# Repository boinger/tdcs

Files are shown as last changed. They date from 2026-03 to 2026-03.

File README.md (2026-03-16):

# tDCS — Open Source Transcranial Direct Current Stimulation

Board layout

A complete, open-source hardware design for a transcranial direct
current stimulation (tDCS) device. The board uses an LM334Z current
regulator with a trimmer potentiometer to deliver an adjustable
0.5-2 mA constant current through sponge electrodes. Designed in
KiCad, fabrication-ready gerbers included for
[OSH Park](https://oshpark.com).

## Disclaimer

**This is an experimental device, not a medical device.** The authors
are not medical professionals. Use entirely at your own risk. Do not
treat this project as medical advice. Passing electric current through
your brain carries inherent risks. Read the published literature and
understand the schematics before attempting anything.

## Getting Started

**Prerequisites:** [KiCad](https://www.kicad.org/) 9.0 or later.

```bash
# macOS
brew install --cask kicad

# Linux (Ubuntu/Debian)
sudo apt install kicad
```

```bash
git clone https://github.com/boinger/tdcs
```

## Workflow

1. Open `tdcs.kicad_sch` in KiCad Schematic Editor — review/edit the circuit
2. Open `tdcs.kicad_pcb` in KiCad PCB Editor
3. **Tools → Update PCB from Schematic** to import components
4. Place components and route traces (reference `board.png` for original layout)
5. Run DRC (**Inspect → Design Rules Checker**)
6. Generate gerbers: `cd gerbers && ./generate-gerbers.sh`

### CLI Commands

```bash
# Export schematic as PDF
kicad-cli sch export pdf -o tdcs-schematic.pdf tdcs.kicad_sch

# Export BOM
kicad-cli sch export bom -o bom.csv tdcs.kicad_sch

# Export netlist
kicad-cli sch export netlist -o board.net tdcs.kicad_sch

# Run ERC (Electrical Rules Check)
kicad-cli sch erc tdcs.kicad_sch

# Generate gerbers (after PCB layout is complete)
cd gerbers && ./generate-gerbers.sh
```

## Getting the PCB Made

1. Upload `gerbers/tdcs.zip` to [OSH Park](https://oshpark.com) (or
   your preferred fab house).
2. Order parts from `bom.csv`.

## Accessories

Beyond the PCB and BOM components, you'll need:

- **Sponge electrodes** — the only electrode type with low enough
  impedance for reliable 2 mA delivery
- **Electrode cables** — speaker cable or lamp cord works fine
- **Pin connectors or banana plugs** — or solder cables directly to
  the board
- **12 V DC power supply** via barrel connector (or a 9 V battery
  if you only need up to ~1 mA)

## Safety

Liebetanz et al. (2009) established a brain-lesion threshold in rats
of **142.9 A/m²** sustained for >10 minutes
([DOI: 10.1016/j.clinph.2009.01.022](https://doi.org/10.1016/j.clinph.2009.01.022)).

This design uses 25 cm² sponge electrodes. Current densities:

| Condition | Current | Density | vs. Threshold |
|---|---|---|---|
| Normal operation | 2 mA | 0.8 A/m² | ~0.6% |
| Regulator failure (max) | 3 mA | 1.2 A/m² | ~0.8% |

Both cases are well below the damage threshold by two orders of
magnitude.

## Other Designs

The original upstream repo has branches for two additional designs:

- **v2** — MSP430-based programmable stimulator with USB power, data
  logging, and software-controlled current (via AD8400 digital pot)
- **v3** — Simplified USB-powered fixed-output (2 mA) stimulator

See [historical/](historical/) for archived blog posts describing
these designs.

## Repository Structure

| Path | Purpose |
|---|---|
| `tdcs.kicad_sch` | Main schematic (KiCad Schematic Editor) |
| `tdcs.kicad_pcb` | Board layout (KiCad PCB Editor) |
| `tdcs.kicad_pro` | KiCad project file |
| `gerbers/` | Gerber output + `generate-gerbers.sh` |
| `gerbers/tdcs.zip` | Ready-to-upload zip for OSH Park |
| `datasheets/` | Component datasheets |
| `historical/` | Archived upstream blog posts, images, and gEDA design files |

## License

All files are licensed
[CC-BY 3.0](https://creativecommons.org/licenses/by/3.0/).
Full text in [LICENSE.txt](LICENSE.txt). Original design by
[Shawn Nock](https://github.com/nocko).

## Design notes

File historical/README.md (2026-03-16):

# Historical Reference Materials

Original design by [Shawn Nock](https://github.com/nocko) (nocko),
published July-August 2012. Upstream repo:
[nocko/tdcs](https://github.com/nocko/tdcs).

These materials were recovered from the Wayback Machine after the
original blog at nocko.se went offline. Archived for provenance and
historical reference.

## Blog Posts (Wayback Machine HTML captures)

- **blog-v1-brain-zapping-is-fun.html** — "Open Source Hardware TDCS"
  (July 30, 2012). Introduces the v1 design, accessories list, and
  safety analysis.
  [Wayback link](https://web.archive.org/web/20160320002608/https://nocko.se/2012/07/30/brain-zapping-is-fun/)

- **blog-v2v3-two-new-designs.html** — "Two new Open tDCS designs"
  (August 8, 2012). Describes the v2 (MSP430 programmable) and v3
  (USB simple) designs.
  [Wayback link](https://web.archive.org/web/20160511003744/https://nocko.se/2012/08/08/opentdcs/)

## Images

- `v1-schematic.png` — v1 circuit diagram (LM334Z current regulator)
- `v1-board-front.png` — v1 PCB front render (OSH Park)
- `v1-board-back.png` — v1 PCB back render (OSH Park)
- `v2-schematic.png` — v2 circuit diagram (MSP430 + FT232RL + AD8400)

## gEDA Design Files (`geda/`)

The original v1 design was created in gEDA. These files were moved
here when the project was ported to KiCad. They are the canonical
source for the original circuit and PCB layout.

- `tdcs.sch` — Main schematic (gschem format)
- `tdcs.pcb` — Board layout (gEDA PCB format)
- `project` — gsch2pcb config: schematics list, output name
- `gafrc` — gschem config: custom symbol library paths
- `attribs` — BOM field template for gnetlist
- `board.cmd` — Pin renaming commands applied during PCB import
- `generate-gerbers.sh.orig` — Original gEDA-based gerber generation script
- `gschem-sym/` — Custom schematic symbols:
  - `current-reg/lm334-1.sym` — LM334Z current regulator (used in v1)
  - `lt1026-1.sym` — LT1026 charge pump (used in v1)
  - `n-jfet.sym` — N-channel JFET (used in v1)
  - `ad6400.sym` — AD6400 (v2 design, unused in v1)
  - `dpst-1.sym` — DPST switch (unused in v1)
  - `ft232rl.sym` — FT232RL USB-to-serial (v2 design, unused in v1)
  - `msp430f21x2-1.sym` — MSP430 microcontroller (v2 design, unused in v1)
  - `st662ab.sym` — ST662AB charge pump (unused in v1)
  - `usbconn.sym` — USB connector (v2/v3 design, unused in v1)
  - `ZXCT1009.sym` — ZXCT1009 current monitor (unused in v1)

## Unused Footprints (`unused-footprints/`)

Custom PCB footprints from earlier design iterations (v2/v3). None are
referenced by the current v1 schematic. Moved here from `packages/`.

- `ct6ep-2.fp` — Copal CT6EP trimmer (alternate footprint)
- `EG 1218-1.fp` — E-Switch toggle
- `Emerson Test Port horizontal.fp` — Emerson test port (horizontal)
- `Emerson Test Port.fp` — Emerson test port (vertical)
- `mill max mini-usb.fp` — Mill-Max mini-USB connector
- `PJ-031D-2.fp` — CUI barrel jack (variant 2)
- `PJ-031D-3.fp` — CUI barrel jack (variant 3)
- `PJ-031D.fp` — CUI barrel jack
- `SJ1-352xN.fp` — CUI 3.5mm audio jack

## Unused Datasheets (`unused-datasheets/`)

Datasheets for components used in v2/v3 designs but not in the current
v1 board. Moved here from `datasheets/`.

- `AD8400_8402_8403.pdf` — Analog Devices digital potentiometer (v2 design)
- `DS_FT232R.pdf` — FTDI FT232R USB-to-serial (v2 design)

## License

All original materials by Shawn Nock are licensed
[CC-BY 3.0](https://creativecommons.org/licenses/by/3.0/).

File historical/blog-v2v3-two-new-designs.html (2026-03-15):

Wayback Machine

8 captures

20 Sep 2015 - 12 Nov 2020

Apr | MAY | Jun
| 11
2015 | 2016 | 2017

success

fail

(https://archive.org/account/login.php) (https://help.archive.org/help/category/the-wayback-machine/)

About this capture

COLLECTED BY

Organization: Internet Archive (https://archive.org/details/webwidecrawl)

The Internet Archive discovers and captures web pages through many different web crawls. At any given time several distinct crawls are running, some for months, and some every day or longer. View the web archive through the Wayback Machine (http://archive.org/web/web.php).

Collection: Wide Crawl Number 14 - Started Mar 4th, 2016 - Ended Sep 15th, 2016 (https://archive.org/details/wide00014)

The seed for Wide00014 was:

- Slash pages from every domain on the web:

-- a list of domains using Survey crawl seeds

-- a list of domains using Wide00012 web graph

-- a list of domains using Wide00013 web graph

- Top ranked pages (up to a max of 100) from every linked-to domain using the Wide00012 inter-domain navigational link graph

-- a ranking of all URLs that have more than one incoming inter-domain link (rank was determined by number of incoming links using Wide00012 inter domain links)

-- up to a maximum of 100 most highly ranked URLs per domain

The seed list contains a total of 431,055,452 URLs
The seed list was further filtered to exclude known porn, and link farm, domains
The modified seed list contains a total of 428M URLs

TIMESTAMPS

loading

The Wayback Machine - https://web.archive.org/web/20160511003744/https://nocko.se/2012/08/08/opentdcs/

Shawn Nock

- About
- Computing
- tDCS

# Two new Open tDCS designs

I think the clever bit was re-purposing the flash memory voltage regulator to power the circuits entirely from USB. Also the electrode interface has been changed to a standard headphone jack. It’ll make it easier to design a case (also, hackers can save money reusing old connectors).

## Version 2: A full-featured programmable stimulator

v2 Schematic

The schematic and incomplete board layout is available in the v2 branch of the Open tTDCS repository (https://web.archive.org/web/20160511003744/https://github.com/nocko/tdcs/tree/v2). The potential feature set is huge:

- Powered and programmed via USB
- Data logging and runtime control via USB
- Programmable current ramping and switching
- Precision current and voltage monitoring
- Auto-trimming of current
- Battery operation available via Minty Boost (https://web.archive.org/web/20160511003744/http://www.ladyada.net/make/mintyboost/) or similar

There is a lot of work to complete before this will be usable. Specifically:

- MSP430 software needs to be written
- Squeezing the design into a 2 layer board is proving challenging
- Hobbyists may be deterred by high part count and SMT parts.

In the next week or two I’ll get the board designed and order prototypes.

## Version 3: USB powered, Simple Stimulator

v3 Board

I designed this board to output 2mA (trimmable +-10%) to be powered by USB with a minimal part count. It’s easy to use and has the following advantages:

- It’s cheap, $8.72/ea.
- It outputs exactly what you probably want, 2mA.
- It’s easy to use. Simply attach electrodes, then plug into USB port.

While I was developing v2, I started wondering if switching noise from the charge pump would effect the current ripple of the LM334Z. With the giant output capacitor I am not too worried, but this design started as a cheap way to check. As it evolved, I think it’s a good choice for a plug-and-play tDCS solution for those who just want cheap, easy and reliable current delivery for home use.

v3 Schematic

Schematic and pcb layout are available in the v3 branch of the Open tTDCS repository (https://web.archive.org/web/20160511003744/https://github.com/nocko/tdcs/tree/v3). I’ve ordered the prototypes and will update with results / scope images.

## How to Build

If you want to build the v3, simply zip the files in the gerber directory and upload to your pcb manufacturer of choice (I use oshpark (https://web.archive.org/web/20160511003744/http://oshpark.com/)). Order the parts listed in bom.txt (https://web.archive.org/web/20160511003744/https://github.com/nocko/tdcs/blob/v3/bom.txt). Solder the parts according to the instructions, and you’re good to go.

- ← Previous
- Archive
- Next →

#### Published

08 August 2012

#### Tags

- tdcs 2
- usb 1
- opentdcs 1

© Shawn Nock 2015

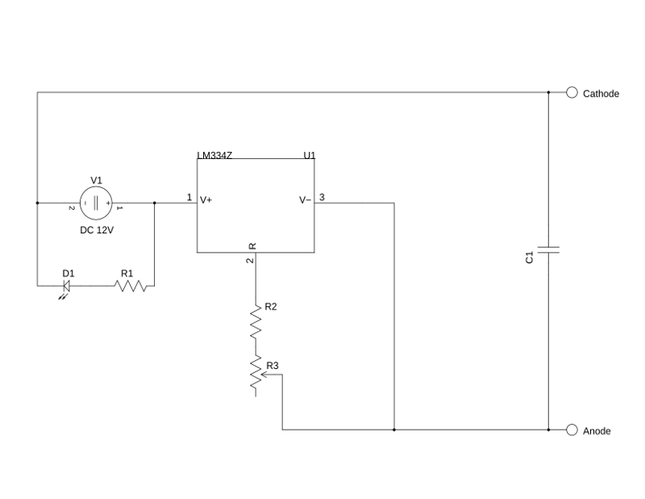
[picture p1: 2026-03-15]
historical/v1-schematic.png

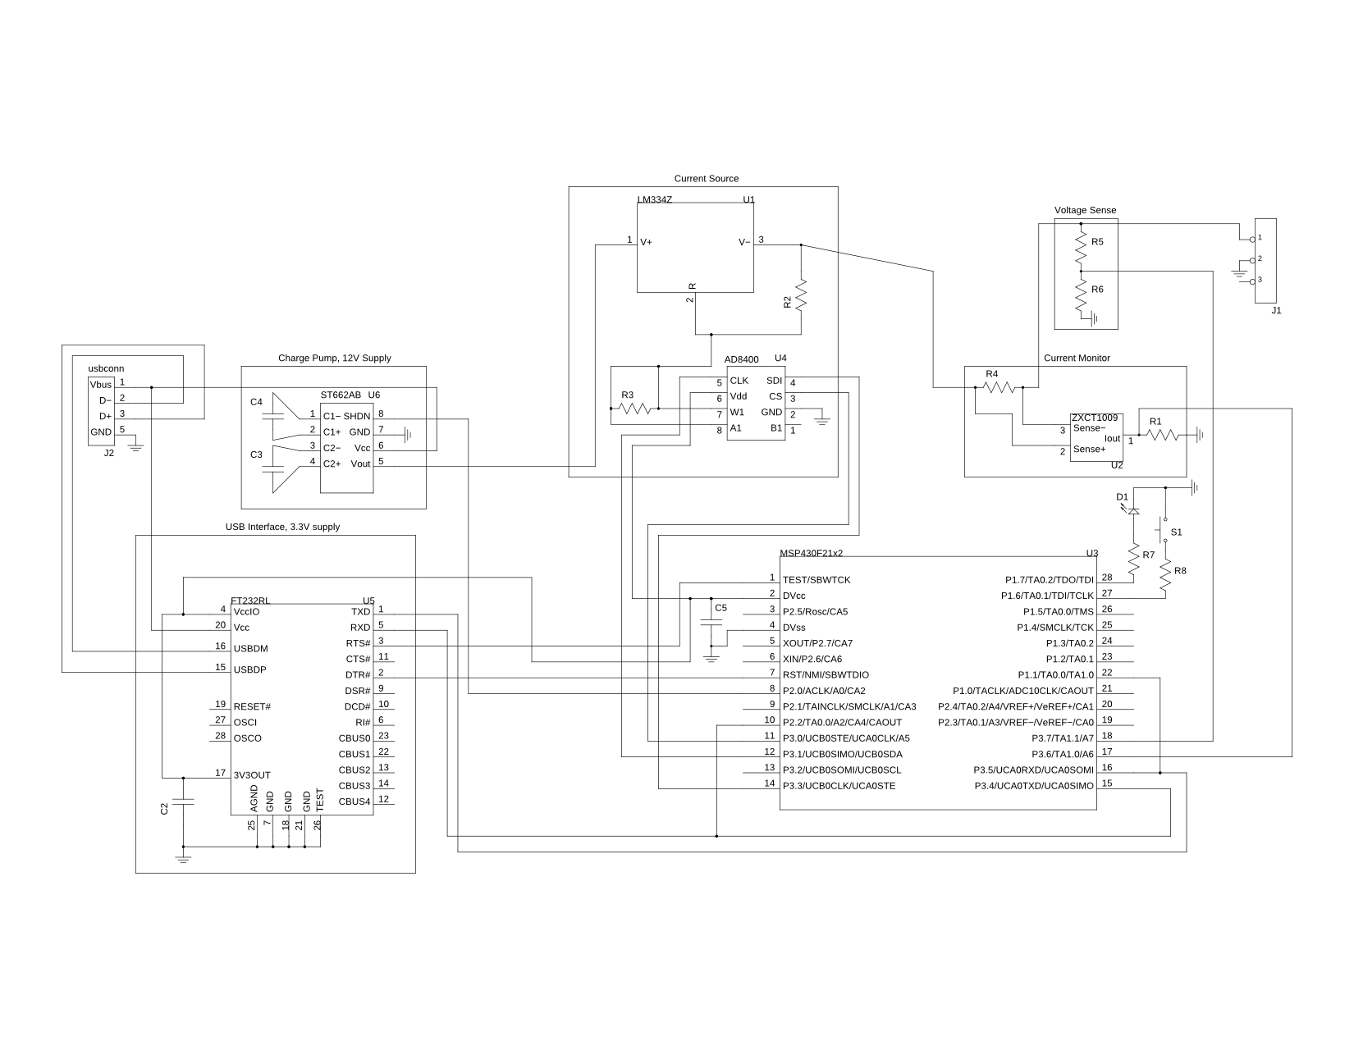
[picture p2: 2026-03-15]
historical/v2-schematic.png

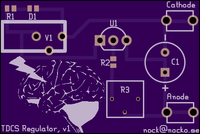
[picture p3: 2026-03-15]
historical/v1-board-front.png

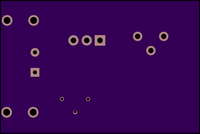
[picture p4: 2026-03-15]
historical/v1-board-back.png

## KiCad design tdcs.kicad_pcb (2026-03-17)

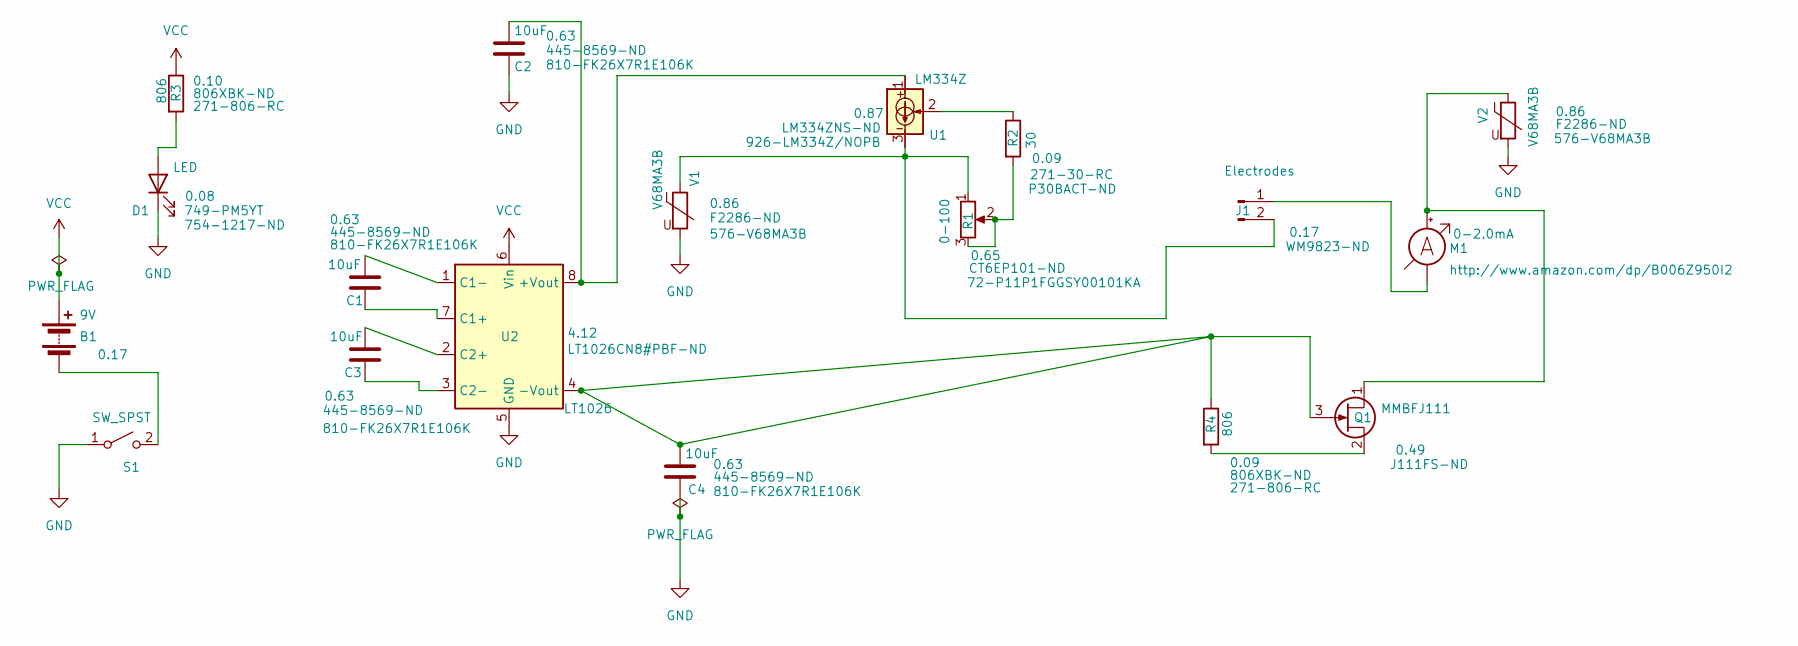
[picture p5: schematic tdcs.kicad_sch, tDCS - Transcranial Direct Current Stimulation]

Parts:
B1: 9V; PinHeader_1x02_P2.54mm_Vertical
C1, C2, C3, C4: 10uF; C_Disc_D5.0mm_W2.5mm_P5.00mm; DigiKey 445-8569-ND
D1: LED; LED_D3.0mm; DigiKey 754-1217-ND
J1: Electrodes; PinHeader_1x02_P2.54mm_Vertical; DigiKey WM9823-ND
M1: 0-2.0mA; PinHeader_1x02_P2.54mm_Vertical
Q1: MMBFJ111; TO-92_Inline; DigiKey J111FS-ND
R1: 0-100; PinHeader_1x03_P2.54mm_Vertical; DigiKey CT6EP101-ND
R2: 30; R_Axial_DIN0207_L6.3mm_D2.5mm_P7.62mm_Horizontal; DigiKey P30BACT-ND
R3, R4: 806; R_Axial_DIN0207_L6.3mm_D2.5mm_P7.62mm_Horizontal; DigiKey 806XBK-ND
S1: SW_SPST; PinHeader_1x02_P2.54mm_Vertical
U1: LM334Z; TO-92_Inline; DigiKey LM334ZNS-ND
U2: LT1026; DIP-8_W7.62mm; DigiKey LT1026CN8#PBF-ND
V1, V2: V68MA3B; R_Axial_DIN0207_L6.3mm_D2.5mm_P7.62mm_Horizontal; DigiKey F2286-ND

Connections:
GND: C2.2, C4.2, D1.1 (K), S1.1 (A), U2.5 (GND), V1.2, V2.2
unnamed: B1.2 (-), S1.2 (B)
unnamed: D1.2 (A), R3.2
unnamed: J1.1, M1.1 (-)
unnamed: J1.2, R1.1, U1.3, V1.1
unnamed: M1.2 (+), Q1.1 (D), V2.1
unnamed: C4.1, Q1.3 (G), R4.1, U2.4 (-Vout)
unnamed: Q1.2 (S), R4.2
unnamed: R1.2, R1.3, R2.2
unnamed: R2.1, U1.2
unnamed: C2.1, U1.1, U2.8 (+Vout)
unnamed: C1.2, U2.7 (C1+)
unnamed: C1.1, U2.1 (C1-)
unnamed: C3.1, U2.2 (C2+)
unnamed: C3.2, U2.3 (C2-)
VCC: B1.1 (+), R3.1, U2.6 (Vin)

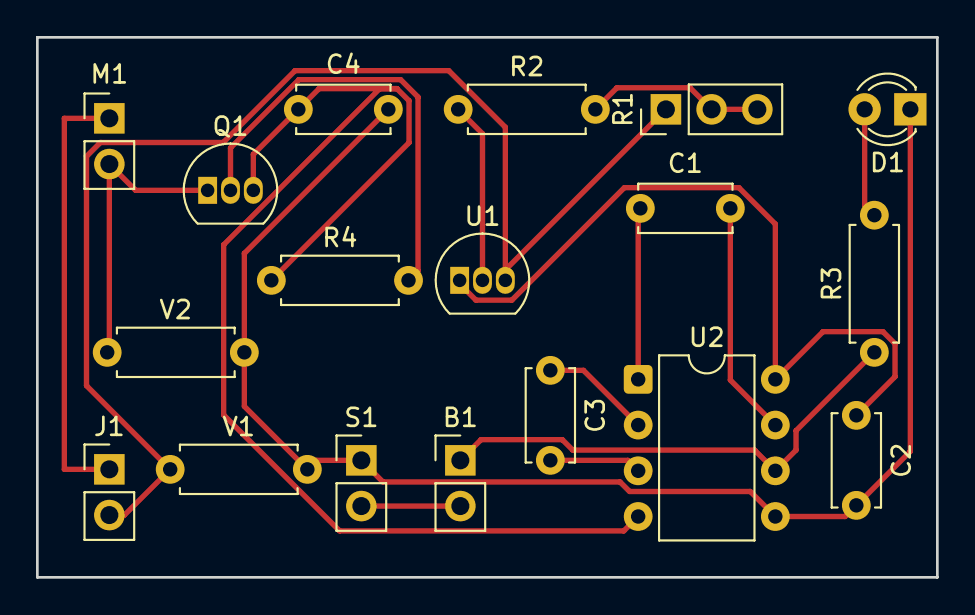
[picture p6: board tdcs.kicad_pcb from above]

Board: 2 copper layers, 50.0 x 30.0 mm, 18 parts (0 on the bottom side), 16 nets.

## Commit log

2026-03-15 Rewrite README, fix paths, archive upstream materials
    - Full README rewrite: project description, safety analysis, disclaimer,
    accessories, workflow, repo structure
    - Add historical/ with archived blog posts and images from nocko.se
    (recovered via Wayback Machine)
    - Fix footprint path in project file (pcb_path → packages)
    - Fix generate-gerbers.sh portability (use $() instead of backticks)
2026-03-16 Port tDCS project from gEDA to KiCad
    gEDA is unmaintained (no releases since 2013, removed from Homebrew).
    lepton-eda fork has broken macOS support. KiCad is the standard
    open-source EDA tool with active development and cross-platform support.
    Schematic port (tdcs.kicad_sch):
    - All 18 components with correct symbols, values, and footprints
    - All 16 nets verified against original board.net
    - Supplier fields (DigiKey, Mouser, Price) carried forward
    - Fixes two wiring bugs in the original gEDA schematic:
    - S1 (switch) was shorted (both pins on same wire) — now functional
    - M1 (ammeter) pin 2 was floating — now properly in series
    - Fixes R1 potentiometer footprint: 2-pin → 3-pin heade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
    [bom.csv, tdcs.kicad_pcb, tdcs.kicad_sch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]
2026-03-16 Add PWR_FLAG symbols to silence ERC power-not-driven errors
    KiCad ERC requires explicit PWR_FLAG markers on power nets to
    confirm they are intentionally driven. Added one on GND and one
    on VCC.
    [tdcs.kicad_sch]
2026-03-16 Rearrange schematic layout for readability, fix LED orientation
    Components repositioned in KiCad GUI for clearer signal flow.
    Fixed D1 (LED) orientation — was reverse-biased after move.
    KiCad project file updated with DRC/ERC settings from GUI.
    [tdcs.kicad_sch, tdcs.sch]
2026-03-17 Complete PCB layout with all components placed and routed
    2-layer board, all 18 THT components placed and traces routed.
    DRC passes clean.
    [tdcs.kicad_pcb]
2026-03-17 Regenerate gerber files from KiCad PCB layout
    7 gerber layers + drill file, zipped for OSH Park upload.
    [tdcs-B_Cu.gbl, tdcs-B_Mask.gbs, tdcs-B_Silkscreen.gbo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]
2026-03-17 Update supplier part numbers and pricing to current (March 2026)
    - R2: DigiKey P30BACT-ND (obsolete) → 30QBK-ND (YAGEO CFR-25JB-52-30R)
    - R2: Mouser 271-30-RC (discontinued) → 603-CFR-25JB-52-30R
    - D1: Mouser 749-PM5YT (wrong part) → 604-WP3A8GD (correct green 3mm LED)
    - U2: added Mouser 584-LT1026CN8#PBF
    - Q1: added Mouser 512-J111
    - R3/R4: Mouser updated to 603-MFR-25FBF52-806R
    - M1: Amazon link updated (old listing dead) → B086Q1HT28
    - All prices updated to current single-quantity pricing
    [tdcs.kicad_sch]

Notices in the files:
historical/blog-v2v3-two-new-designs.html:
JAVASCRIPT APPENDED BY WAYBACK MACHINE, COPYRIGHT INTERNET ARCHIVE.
